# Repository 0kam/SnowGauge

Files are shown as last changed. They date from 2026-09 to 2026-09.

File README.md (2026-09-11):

<p align="center">
  <picture>
    <source media="(prefers-color-scheme: dark)" srcset="docs/assets/logo/logo_dark_800.png">
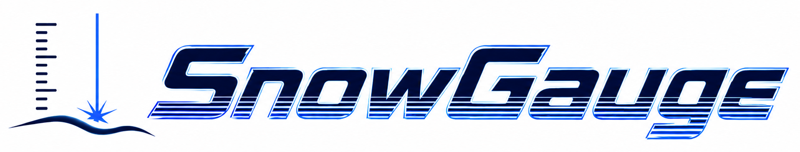
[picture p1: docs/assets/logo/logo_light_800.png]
SnowGauge
    
  </picture>
</p>

# SnowGauge

山岳・亜高山帯の無人サイトで 2 年間動く、低価格・低消費電力の積雪深ロガーです。
近赤外レーザー測距（TFmini Plus）で雪面までの斜距離を測り、IMU の傾斜で補正して積雪深に換算します。
スマホ（Android Chrome）の Web Bluetooth ページで時刻合わせ・データ回収・設定を行い、電池だけで越冬します。

*SnowGauge is a low-cost, low-power snow-depth logger (NIR laser ToF + XIAO nRF52840 Sense, Zephyr firmware, Web Bluetooth field app). Documentation is in Japanese; the developer docs (`firmware/README.md`, `docs/app/README.md`, `docs/record_format.md`) are in English.*

## はじめての方へ（この順に読む）

| 段階 | 読むもの | 内容 |
|---|---|---|
| 1. 部品を買う | [docs/01_parts.md](docs/01_parts.md)（[CSV](docs/01_parts.csv)） | 購入リスト。基板版・ブレッドボード版・TSD20 版の差分 |
| 2. 組み立てる | [docs/02_assembly.md](docs/02_assembly.md) | ブレッドボード（[配線ガイド](https://0kam.github.io/SnowGauge/breadboard_guide.html)）／基板 v1.2／筐体（検討中） |
| 3. ファームを書く | [docs/03_firmware.md](docs/03_firmware.md) | [Release](https://github.com/0kam/SnowGauge/releases) からダウンロードして USB で書き込み |
| 4. アプリを入れる・使う | [docs/04_app.md](docs/04_app.md) | **アプリ: https://0kam.github.io/SnowGauge/app/** 設置時・巡回時の手順 |
| 5. データを見る | [docs/05_data.md](docs/05_data.md) | CSV の列、品質フラグ、積雪深の再計算 |

文書一覧と「どこを直すとき何を更新するか」は [docs/README.md](docs/README.md) にあります。

## 現地アプリ

スマホの Chrome で https://0kam.github.io/SnowGauge/app/ を開き「ホーム画面に追加」すると、圏外でも起動するアプリになります（[使い方](docs/04_app.md)）。本体なしで画面を試すには [デモ表示](https://0kam.github.io/SnowGauge/app/?demo=1)。

<table align="center"><tr>
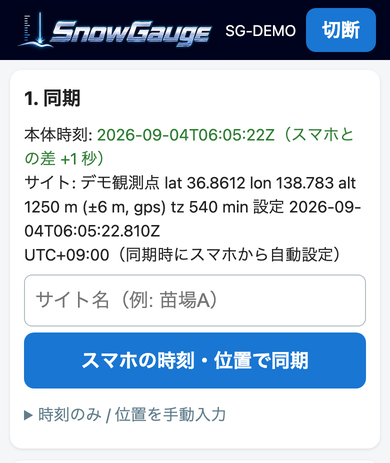
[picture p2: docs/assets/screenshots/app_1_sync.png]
同期
  <td valign="top" width="25%"></td>
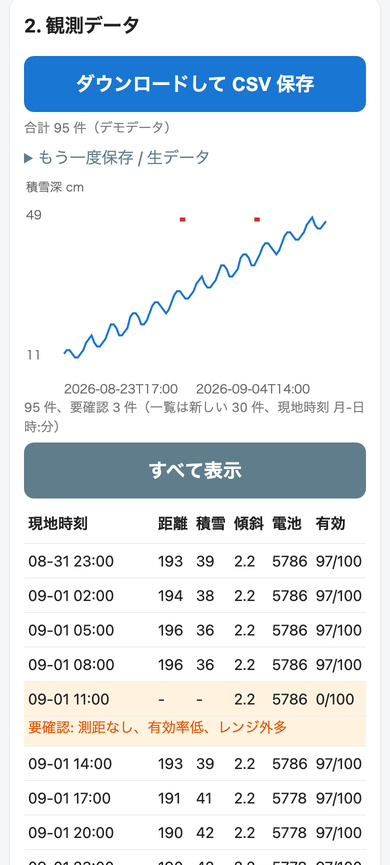
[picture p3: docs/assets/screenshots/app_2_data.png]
観測データ
  <td valign="top" width="25%"></td>
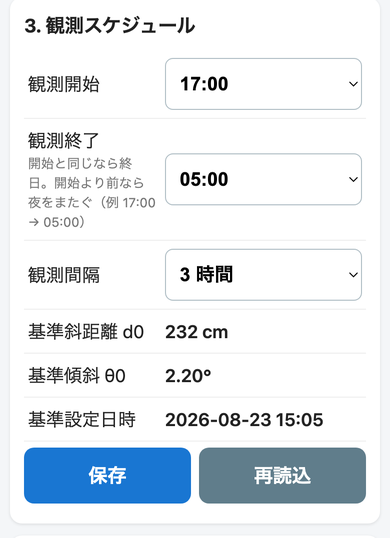
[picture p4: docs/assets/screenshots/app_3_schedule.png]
観測スケジュール
  <td valign="top" width="25%"></td>
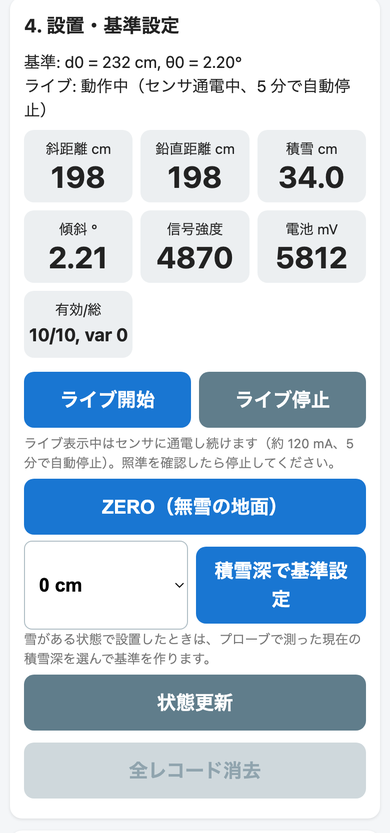
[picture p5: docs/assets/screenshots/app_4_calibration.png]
設置・基準設定
  <td valign="top" width="25%"></td>
</tr><tr>
  <td align="center">1. 同期</td><td align="center">2. 観測データ</td><td align="center">3. スケジュール</td><td align="center">4. 設置・基準設定</td>
</tr></table>

## 主な仕様

- 測距: TFmini Plus（近赤外 ToF）。安価な代替として TSD20 版を A/B 比較予定
- MCU: Seeed XIAO nRF52840 Sense（BLE、IMU 内蔵）、Zephyr（nRF Connect SDK v3.4.0）
- 電源: リチウム単 3（Energizer L91）×4。実測スリープ 26 µA（BLE アドバタイズ込み）、測定 1 回 0.037 mAh
- 記録: 40 バイト/回、QSPI フラッシュ上の LittleFS ＋ 内蔵フラッシュへのミラー。8 回/日で 2 年以上
- 通信: BLE（アドバタイズに電池・件数・最終値、SMP でファイル取得と時刻同期、キャリブレーション用 GATT）
- 現地 UI: Web Bluetooth ページ（PWA、オフライン動作、手袋前提の大きなボタン）

## 開発者向け

- 設計仕様書（要件・設計判断・改版履歴）: [SnowGauge_設計仕様書_v0.16.md](SnowGauge_設計仕様書_v0.16.md)
- 基板（KiCad、ガーバー、ピンマップの正）: [pcb/README.md](pcb/README.md)
- ファームウェアのビルド・シェル: [firmware/README.md](firmware/README.md)
- アプリの構成（SMP クライアントの流用方法）: [docs/app/README.md](docs/app/README.md)
- レコード形式・CSV 列定義: [docs/record_format.md](docs/record_format.md)
- 作業引き継ぎ（AI エージェント向け）: [CLAUDE.md](CLAUDE.md)

## 状態（2026-09-04）

基板 v1.2 発注済み（到着 9/10 ごろ）。ブレッドボードでファームウェア（ステップ 1〜4）とアプリの実機確認まで完了。TSD20 版ファームウェア（ステップ 5）は実装・ビルド済みで、ブレッドボード（U2 を F33 に差し替え）での実機確認待ち。次は基板到着後の再測定、筐体。

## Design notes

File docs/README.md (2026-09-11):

# SnowGauge 文書一覧と更新マップ

## 読む順（ユーザー向け）

| # | 文書 | 対象 | 内容 |
|---|---|---|---|
| 1 | [01_parts.md](01_parts.md) / [01_parts.csv](01_parts.csv) | 部品を買う人 | 購入リスト（BOM の唯一の正） |
| 2 | [02_assembly.md](02_assembly.md) | 組み立てる人 | ブレッドボード、基板 v1.2、筐体（検討中） |
| 2' | [breadboard_guide.html](https://0kam.github.io/SnowGauge/breadboard_guide.html) / [breadboard_guide_tsd20.html](https://0kam.github.io/SnowGauge/breadboard_guide_tsd20.html) | 同上 | ブレッドボード配線の図解（生成物。TFmini Plus 版 / TSD20 版、§5 に組み替え手順） |
| 3 | [03_firmware.md](03_firmware.md) | 書き込む人 | Release からのダウンロードと USB 書き込み |
| 4 | [04_app.md](04_app.md) | 現地作業する人 | アプリのインストールと設置・巡回手順 |
| 5 | [05_data.md](05_data.md) | 解析する人 | CSV の読み方、品質フラグ、再計算 |

## 技術文書（開発者向け）

| 文書 | 内容 |
|---|---|
| [../SnowGauge_設計仕様書_v0.16.md](../SnowGauge_設計仕様書_v0.16.md) | 要件・設計判断・電力収支・改版履歴。全文改版制（変更のたびに版を上げてファイル名も変える） |
| [../pcb/README.md](../pcb/README.md) | **ピンマップと電気トポロジの正**。基板は `pcb/generate_board.py` から生成（手編集禁止） |
| [../firmware/README.md](../firmware/README.md) | ビルド、書き込み、ベンチ用シェルコマンド |
| [record_format.md](record_format.md) | 40 バイトレコード、フラッシュ配置、CSV 列定義 |
| [coordinate_system.md](coordinate_system.md) | **基板の取付姿勢と IMU 座標系、tilt / pitch / roll の定義の正**（図付き） |
| [app/README.md](app/README.md) | Web Bluetooth ページの構成と他ロガーへの流用 |
| [tsd20_protocol.md](tsd20_protocol.md) | TSD20（廉価版センサ）の UART 仕様とファームウェア変種の実装メモ |
| [measurements/](measurements/) | 実測記録（`YYYY-MM-DD_topic.md`） |
| [archive/](archive/) | 旧版（v1.2 以前の回路。使わないこと） |
| [../CLAUDE.md](../CLAUDE.md) | AI エージェント向けの作業引き継ぎ（現状・決定事項・次の一手） |

## 更新マップ：何を変えたら、どの文書を直すか

| 変更 | 必ず更新するもの | あわせて確認 |
|---|---|---|
| **ピン割り当て・回路トポロジ** | `pcb/generate_board.py` → 再生成・DRC・ガーバー、`pcb/README.md`、`firmware/boards/*.overlay`、`docs/gen_breadboard.py`（PARTS）→ `breadboard_guide.html` と `--tsd20` で `breadboard_guide_tsd20.html` を再生成、`docs/assets/figures/gen_component_orientation.py`（部品の向きの図）を再実行 | 02_assembly.md、01_parts.md、仕様書 §4、CLAUDE.md の Key GPIO |
| **部品・数量・購入先** | `docs/01_parts.md` と `01_parts.csv` | 仕様書 §6（要約のみ）、`pcb/README.md` の追加部品欄 |
| **レコード形式**（フィールド追加・版上げ） | `firmware/src/record.h/.c`、`docs/record_format.md`、`docs/app/app.js` の `RECORD_SCHEMA`、`tools/decode_records.py` | 05_data.md、仕様書 §4.4 |
| **CSV の列** | `docs/app/app.js` の `CSV_COLUMNS`/`exportCSV`、`docs/record_format.md` | 05_data.md |
| **設定キー**（スケジュール・基準など） | `firmware/src/config.h/.c`、`docs/app/app.js` の `SETTINGS_SCHEMA` | 04_app.md、仕様書 §4.6 |
| **BLE**（アドバタイズ内容・GATT・SMP） | `firmware/src/ble_adv.h`、`cal_gatt.h`、`docs/app/app.js`/`smp.js` | 仕様書 §12、04_app.md |
| **アプリ UI** | `docs/app/index.html`、`app.js`（`APP_VERSION` を上げる）、`sw.js`（`CACHE` 名を上げる） | 04_app.md（ボタン名を一致させる） |
| **ファームウェアのリリース** | GitHub Release（タグ `fw-YYYY-MM-DD`、.uf2 / _dfu.zip / .hex）、`docs/03_firmware.md` のリンク | `firmware/README.md`、CLAUDE.md |
| **電流・電池寿命の実測** | `docs/measurements/YYYY-MM-DD_*.md` | 仕様書 §7.1、README の主な仕様 |
| **基板の取付姿勢・傾斜の定義** | `firmware/src/tilt_lsm6dsl.c`、`Kconfig` の `SNOWGAUGE_SENSOR_AXIS`、`docs/coordinate_system.md` と `docs/assets/figures/gen_coordinate_system.py`（図を再生成） | record_format.md、05_data.md、02_assembly.md、仕様書 §4.5 |
| **設計判断の変更** | 仕様書（版を上げ、§14 改版履歴に 1 行） | CLAUDE.md の決定事項 |

原則: 同じ事実を 2 か所に書かない。書く場合は片方を「正」と決めてもう片方からリンクする。

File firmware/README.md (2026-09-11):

# SnowGauge firmware

Zephyr / nRF Connect SDK application for the Seeed XIAO nRF52840 Sense on
SnowGauge PCB v1.2 (or the equivalent breadboard, `docs/breadboard_guide.html`).

- SDK: **nRF Connect SDK v3.4.0** (installed with `nrfutil sdk-manager`)
- Board target: `xiao_ble/nrf52840/sense`
- Pin map source of truth: [`pcb/README.md`](../pcb/README.md)
- User-facing docs (Japanese): [`docs/03_firmware.md`](../docs/03_firmware.md) (flashing), [`docs/04_app.md`](../docs/04_app.md) (field app), [`docs/05_data.md`](../docs/05_data.md) (data)

## Status: step 5 verified (2026-09-07) — TSD20 sensor variant runs on the breadboard; steps 1–4d complete and verified (32 µA sleep incl. adv)

| Module | File | Purpose |
|---|---|---|
| Sensor rail | `src/sensor_rail.c` | D10 = SENSOR_EN. Parks the sensor UART (pins Hi-Z) *before* cutting the rail (ghost-power countermeasure); calls `lidar_start()` once the rail is up |
| LiDAR | `src/lidar.h`, `src/lidar.c` | Sensor abstraction: interrupt-driven UART receiver, N-sample burst → median / variance / quality counters. Sets the baud rate at run time from the backend. Backend chosen by the Kconfig choice `SNOWGAUGE_SENSOR` |
| TFmini Plus | `src/tfmini.c` | Default backend: 9-byte frames, cm, strength + chip temperature, 115200 baud, frame-rate / save commands |
| TSD20 | `src/tsd20.c` | `overlay-tsd20.conf` backend: 4-byte frames, mm → cm, sentinel 50000, no strength / temperature, 460800 baud, "start ranging" after the rail settles, frame-rate command. Protocol: `docs/tsd20_protocol.md` |
| Battery | `src/battery.c` | A0 via SAADC (gain 1/6, 40 µs acquisition for the 500 kΩ source). Valid only while the rail is on; Vbat = node × 2 |
| Tilt | `src/tilt.h`, `src/tilt_lsm6dsl.c` | `TiltSensor` abstraction; LSM6DS3TR-C implementation (accel only, 52 Hz burst, powered down between reads). Deferred init: the board's regulator delay is too short for the chip. Tilt = angle between gravity and the LiDAR axis in the IMU frame: **−Y** (PCB vertical in the enclosure: USB left, sensor terminal J2 up; default since 2026-09-11), +Y (the 2026-09-07 mount, USB right) or ±Z (flat board, `overlay-flat.conf`); definitions and figure in `docs/coordinate_system.md` |
| Measure | `src/measure.c` | tilt → rail on → Vbat → N frames → Vbat → rail off; `sensor_lock` mutex shared with the calibration live mode. 0 frames → one power-cycle retry (`CONFIG_SNOWGAUGE_LIDAR_RETRY`, 1 s off, TSD20 gets stop → start), record flag RETRIED |
| Power | `src/power.c` | Green LED pulse; checks that the QSPI flash runs under runtime PM (deep power-down between accesses) |
| USB PM | `src/usb_pm.c` | USB device enabled only while VBUS is present (board default keeps HFXO+USBD on: 1.8 mA) |
| Record | `src/record.c` | 40-byte record v1 encode/decode with CRC-16 (`docs/record_format.md`); flag bit 6 marks records from the TSD20 build |
| Storage | `src/storage.c` | LittleFS on the QSPI (`/lfs1/rec_YYYYMM.bin`) + raw append-only mirror in internal flash; restores clock/seq at boot |
| Clock | `src/timekeeping.c` | Emulated RTC behind the `rtc` alias; UNSET / ESTIMATED / SYNCED state. Checkpoint in NVS (`sgt/epoch`) every `CONFIG_SNOWGAUGE_TIME_SAVE_MIN` (60) and 2 s after every external sync; at boot the later of the newest record and the checkpoint seeds the estimate |
| Config | `src/config.c` | Zephyr settings (`sg/sched/*`, `sg/cal/*`) exposed over the SMP settings group; scheduler (local time window + interval, tz offset) and the calibration reference d0/θ0 |
| BLE adv | `src/ble_adv.c` | Connectable advertising 1–2 s, name `SG-TFM-XXXX` (TSD20 build: `SG-TSD-XXXX`), Manufacturer Data with Vbat / record count / last distance / flags (layout in `ble_adv.h`); restarts advertising after a disconnect |
| SMP | `src/smp_mgmt.c` | mcumgr hooks: os datetime get/set → app clock, fs access hook (a read of `rec_*.bin` unlocks the BLE ERASE), over BLE and over the USB shell |
| Calibration GATT | `src/cal_gatt.c` | Custom service (UUIDs in `cal_gatt.h`): live notify (dist/strength/tilt/vbat/quality, 5 min timeout, stops on disconnect), control write (live on/off, ZERO, reference from probed depth, ERASE + token), status read (d0/θ0/set epoch/live/busy/seq) on its own work queue |
| Diag | `src/diag.c` | Reset cause (hwinfo, cleared after reading), consecutive-reset counter in NVS (`sgd/boots`; GPREGRET2 is wiped by a watchdog reset, measured 2026-09-07), fatal reason in GPREGRET2 (soft reset only), hold-off, measurement halt past `CONFIG_SNOWGAUGE_BOOT_MAX_RESETS` resets, one line per boot in `/lfs1/boot.log`; `k_sys_fatal_error_handler` reboots on exceptions/panics instead of halting |
| Watchdog | `src/wdt_mon.c` | nRF52 WDT (`CONFIG_SNOWGAUGE_WDT_TIMEOUT_S` = 120 s, runs in sleep) fed by a supervisor on the system work queue only while the scheduler loop (2 h), a running measurement (60 s) and BLE advertising are all alive |
| Shell | `src/shell_cmds.c` | Bench commands over USB CDC ACM (table below) |

Phone / PC UI: the Web Bluetooth page at **https://0kam.github.io/SnowGauge/app/** (source `docs/app/`, see `docs/app/README.md`). Bench SMP from the Mac: `tools/smp_datetime.py` (pip install smpclient); shell scripting: `tools/sgshell.py` (pyserial). Sleep-current results: `../docs/measurements/2026-09-03_breadboard_current.md`. The TSD20 variant (step 5) was verified on the breadboard on 2026-09-07 (U2 = NJU7223F33, `docs/breadboard_guide_tsd20.html`): 100 frames / 499 ms, 0 checksum errors, records flagged SENSOR_TSD20, one measurement = 0.0098 mAh, sleep 36 µA (`docs/measurements/2026-09-07_tsd20_breadboard_current.md`). The TFmini build after the lidar refactor was re-verified the same day (100 frames / 1010 ms, name `SG-TFM-XXXX`). Details in `docs/tsd20_protocol.md`.

## Prebuilt binaries

Firmware builds are published as GitHub Releases, tag `fw-YYYY-MM-DD`. Current:
**https://github.com/0kam/SnowGauge/releases/tag/fw-2026-09-07**

| Asset | Use |
|---|---|
| `snowgauge_fw_2026-09-07b.uf2` | UF2 drag-and-drop onto the `XIAO-SENSE` drive (Windows / Linux / older macOS) |
| `snowgauge_fw_2026-09-07b_dfu.zip` | Serial DFU package for `adafruit-nrfutil` (required on macOS 26); already built with `--sd-req 0xFFFE` |
| `snowgauge_fw_2026-09-07b.hex` | Application hex (linked at 0x27000) for building your own package |
| `snowgauge_fw_2026-09-07b_tsd20.uf2` / `_tsd20_dfu.zip` / `_tsd20.hex` | The same three files for the **TSD20 variant** (U2 = NJU7223F33; BLE name `SG-TSD-XXXX`) |

Step-by-step flashing instructions for non-developers: [`docs/03_firmware.md`](../docs/03_firmware.md). The app requires this release or newer (settings group + calibration service).

## Build

One-time: install nrfutil and the SDK (already done on the dev Mac; `~/.local/bin/nrfutil`).

```bash
nrfutil sdk-manager install v3.4.0
```

Build inside the SDK toolchain environment. `west` must be started from the SDK workspace (`/opt/nordic/ncs/v3.4.0`), so pass absolute paths:

```bash
cd /opt/nordic/ncs/v3.4.0 && nrfutil sdk-manager toolchain launch --ncs-version v3.4.0 -- west build -d "$REPO/firmware/build" -b xiao_ble/nrf52840/sense "$REPO/firmware"
```

Add `-p` after `west build` for a pristine rebuild; `-- -DEXTRA_CONF_FILE=overlay-auto60.conf` builds the bench variant that measures every 60 s. Output: `firmware/build/firmware/zephyr/zephyr.uf2` and `zephyr.hex` (sysbuild layout).

Host regression check: run `python3 firmware/tests/test_regressions.py` from the repository root (Python 3 and `cc` required). It runs the firmware functions with stubbed hardware/settings to check reset backoff, BLE wakeups, measurement success and settings errors; it does not validate hardware timing or brown-outs.

**Sensor variants** (Kconfig choice `SNOWGAUGE_SENSOR`, same board overlay, same pins):

| Build | Sensor / U2 | Extra args | BLE name |
|---|---|---|---|
| default | TFmini Plus / NJU7223F50 (5 V) | none | `SG-TFM-XXXX` |
| TSD20 | PONO TSD20 / NJU7223F33 (3.3 V) | `-- -DEXTRA_CONF_FILE=overlay-tsd20.conf` (use a separate build dir, e.g. `-d firmware/build-tsd20`) | `SG-TSD-XXXX` |

`overlay-flat.conf` selects the flat-board tilt axis (IMU Z) for a breadboard lying on the bench; without it a flat board reads tilt ≈ 90°. The previous vertical mount (USB right) is `CONFIG_SNOWGAUGE_SENSOR_AXIS_POS_Y=y` in a conf fragment of its own. Both overlays can be combined: `-DEXTRA_CONF_FILE="overlay-tsd20.conf;overlay-auto60.conf"`. A TSD20 build on a TFmini board (or vice versa) is harmless but reads no distance (`lidar info` shows which variant is running).

## Flash (stock Adafruit bootloader, no debugger needed)

The app is linked at 0x27000, after the Adafruit bootloader, so the bootloader is preserved and the board can always be re-flashed.

**UF2 (Windows / Linux / older macOS):** disconnect the battery (**never USB and battery at the same time** unless jumper ⑩ is pulled — see the breadboard guide), connect USB-C, double-tap reset, copy `firmware/build/firmware/zephyr/zephyr.uf2` onto the `XIAO-SENSE` drive.

**Serial DFU (needed on macOS 26, which cannot mount the XIAO's UF2 drive):**

```bash
pip install adafruit-nrfutil
adafruit-nrfutil dfu genpkg --dev-type 0x0052 --sd-req 0xFFFE --application firmware/build/firmware/zephyr/zephyr.hex snowgauge.zip
```

Put the board in the bootloader (double-tap reset, or type `dfu` in the firmware shell), then:

```bash
adafruit-nrfutil dfu serial --package snowgauge.zip -p /dev/cu.usbmodem* -b 115200 --singlebank
```

`--sd-req 0xFFFE` (any SoftDevice) matters: with `0x00` the bootloader rejects the package and resets mid-transfer.

Release assets are produced from the same build: `zephyr.uf2` and `zephyr.hex` renamed, plus the `genpkg` zip above. The TSD20 build goes into the same release tag as `snowgauge_fw_<date>_tsd20.uf2` / `_tsd20_dfu.zip` / `_tsd20.hex`.

## Shell (USB CDC ACM, prompt `sg:~$ `, 115200)

Open the USB serial port (`/dev/cu.usbmodem*`, `COMx`, `/dev/ttyACM0`) with e.g. `screen`, Tera Term or `tools/sgshell.py`, press Enter for the prompt.

| Command | Purpose |
|---|---|
| `help` | list commands (`cal` and `cfg` present = step 4d firmware) |
| `rail on` / `rail off` / `rail status` | sensor rail (boots OFF; `rail off` parks the UART first) |
| `lidar raw [ms]` | live frames for `ms` (needs `rail on`); TSD20 build prints mm |
| `lidar read [n] [timeout_ms]` | n-frame burst: median / variance (+ strength / temperature on the TFmini) |
| `lidar rate <hz>` / `lidar save` | sensor frame rate (TFmini: volatile until saved; TSD20: no save command) |
| `lidar info` | sensor variant, baud, capture parameters, Vbat guard |
| `lidar bytes [ms]` / `lidar baud <rate>` / `lidar start` / `lidar tx <hex…>` | debug: raw RX hex dump, run-time baud change, send the start-streaming command, send arbitrary bytes |
| `tfmini …` / `tsd20 …` | alias of `lidar` in the matching build (old scripts keep working) |
| `batt` | battery voltage (pulses the rail if it is off) |
| `tilt [n]` | IMU tilt / pitch / roll from n averaged samples |
| `measure` | one full cycle, stored as a record (flag MANUAL), printed as CSV |
| `auto [s]` | bench auto-measurement period (0 = off); overrides the schedule |
| `rec count` / `rec ls` / `rec dump [n]` / `rec hex [n]` | record count + storage state / files on `/lfs1` / newest n records as CSV (0 = all) / raw hex for `tools/decode_records.py --hex` |
| `rec erase ERASE` | delete all record files + erase the mirror |
| `time [set <epoch>]` | show / set the clock (UTC seconds, `date +%s`); shows synced / estimated / unset |
| `cfg show` | schedule, tz, calibration reference, next scheduled measurement |
| `cfg sched <HH:MM> <HH:MM> <interval_min> [tz_min]` | set the schedule (start == end: all day; start > end: spans midnight; interval 0: off) |
| `cal zero [depth_cm]` | take the reference (ZERO on bare ground, or from a probed snow depth: `d0 = d + depth/cos(tilt)`) |
| `cal clear` | clear the reference |
| `cal live [off]` | live-mode state; `off` stops it (start only from the BLE page) |
| `ble [adv <min_ms> [max_ms]]` | advertising status / interval (`ble adv 0` stops) |
| `diag [log]` | reset cause / boot counter / last fatal reason; `log` also prints `/lfs1/boot.log` |
| `wdt [stall main\|measure\|ble]` | watchdog supervisor status; `stall` simulates a stuck subsystem (reset within ~150 s) |
| `hang` / `fault` / `panic` | TEST: lock the CPU (watchdog reset after 120 s) / CPU exception / `k_panic()` (both reboot through the fatal handler; `diag` on the next boot shows `fatal=…`) |
| `reboot` | warm reset into the application |
| `dfu` | reboot into the Adafruit bootloader (then run `adafruit-nrfutil dfu serial`) |
| `device list`, `sensor get lsm6ds3tr-c@6a` | Zephyr built-ins (debug) |

Bench test (breadboard STEP 5 / PCB bring-up): `rail status` → `rail on` (sensor node = 5 V with the TFmini LED on / 3.3 V for the TSD20) → `lidar raw 500` → `lidar read 100` → `batt` → `rail off` (sensor node = 0 V) → `measure`. Measured on the breadboard (2026-09-03, 6 V bench supply): `vbat = 5624 mV`, 100 frames / 997 ms, `cksum_err=0`, median 197 cm, strength ~6830, chip temp 65 °C. If the TFmini stays dimly alive with the rail off, the UART is not parked — check that `rail off` returned 0.

Boot behaviour worth knowing on the bench: the first *scheduled* measurement is held off for 10 min × consecutive-reset count (`CONFIG_SNOWGAUGE_BOOT_HOLDOFF_MIN`, multiplier capped at 12); `measure` and `auto` bypass this hold-off. The NVS counter clears after the first attempted sensor rail burst whose record is successfully stored (manual or scheduled), or on BLE connection; elapsed time alone never clears it. This proves the board survived the rail load, not that the sensor returned a valid distance: zero valid frames or capture errors still clear the counter when the record is stored. Bursts skipped by the low-battery guard (`lidar_ret == -ENOTSUP`), measurement-cycle errors and storage failures retain the counter. At `CONFIG_SNOWGAUGE_BOOT_MAX_RESETS` (12), scheduled measurements (including `auto`) halt while BLE keeps advertising (flag MEAS_HALTED). **Rebooting or power-cycling alone does not recover a halted unit.** Connect over BLE to drop the halt and multiplier immediately (the base 10 min hold-off remains), or run a manual `measure` with a non-skipped burst and successfully store its record, then reboot. Counter-clear write failures are logged and retried on the next stored, non-skipped burst or BLE connection. Vbat < 4600 mV skips the TFmini burst. Every boot appends a line to `/lfs1/boot.log` (`diag log`), e.g. `~2026-09-07T10:00:00Z boot=2 cause=watchdog fatal=none hw=0x2 fw=TFmini Plus`.

## Shell output fields

`weak` = strength < 100 (Benewake: unreliable), `sat` = strength 65535 (over-exposed), `invalid` = distance sentinel (TFmini 0 / 65535 cm, TSD20 50000 mm) with acceptable strength, `cksum_err` = frames dropped by checksum. The TSD20 build has no `weak` / `sat` / strength / chip-temperature lines. `var` is the sample variance in cm² over the valid frames.

## Notes / decisions pending

- **No MCUboot / BLE DFU in v1 (decided 2026-09-02, spec v0.11)**: the XIAO ships with the Adafruit UF2 bootloader at 0x0 and installing MCUboot would overwrite it, which needs an SWD probe. The firmware is flashed over USB as UF2 / serial DFU; field updates mean opening the enclosure and plugging in USB (battery disconnected).
- Build reproducibility: the SDK version is pinned here (v3.4.0) and the build uses the SDK's own workspace. There is **no `west.yml` manifest in this repo**; add one for a self-contained workspace when the build moves to CI.
- No pairing: anyone nearby can erase (token-protected, and only after a download since boot) or change settings. PIN later if needed.
- WDT on since 2026-09-07 (120 s). The nRF52 WDT keeps running across a soft reset into the Adafruit bootloader; the bootloader (0.6.1 and later, `lib/sdk11/.../bootloader.c` `wait_for_events()`) feeds a running WDT in its DFU wait loop, so `dfu` + serial DFU keep working. Verify the bootloader version on a new board (it is the USB `bcdDevice` while in bootloader mode: `system_profiler SPUSBDataType`).

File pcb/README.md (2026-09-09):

# SnowGauge PCB v1.2 (TFmini Plus / TSD20 common board)

- Board: **64 x 50 mm**, 2-layer, all through-hole. Bottom layer is a GND pour.
- Mounting: 4x M3 (3.2mm) holes at the corners, **57 x 43 mm** center spacing (3.5mm from every edge; hole centers at (3.5, 3.5) / (60.5, 3.5) / (3.5, 46.5) / (60.5, 46.5) from the board's top-left corner).
- Fits the previous prototype enclosure (Takachi BCAP091208G, inner 66 x 96 mm) with the 50mm side across the width.
- Battery terminal J1 exits at the bottom edge; TFmini terminal J2 exits at the right edge.
- Generated programmatically: [generate_board.py](generate_board.py) → `SnowGauge.kicad_pcb` (KiCad 10). DRC: 0 errors, 0 unconnected.
- One board serves both variants: **U2 = NJU7223F50 for TFmini Plus / NJU7223F33 for TSD20** (same pinout).

## Ordering (JLCPCB, ~1 week to Japan)

1. Go to jlcpcb.com → "Add gerber file" → upload `SnowGauge_v1.2_gerbers.zip`
2. Settings: 2 layers, 64x50mm (auto-detected), qty 5 (or 10), 1.6mm, HASL, green — all defaults are fine
3. Shipping: **DHL or OCS Express** (this is what makes it arrive in ~3-4 days; economy mail takes weeks)

## Firmware pin map (matches this board — the single source of truth)

| XIAO pin | Net | Function |
|---|---|---|
| A0 (D0) | ADC_NODE | Battery voltage = reading x2. Divider hangs on VBAT_SW, so **enable SENSOR_EN, then read A0** (v1.2: Q3/R6/D3 deleted — node is 0V during sleep, never above VDD) |
| D4 / D5 | I2C_SDA / I2C_SCL | Spare I2C header J3 (future external IMU) |
| D6 (TX) | UART_TX_MCU | → 1k (R7) → TFmini RX (white) |
| D7 (RX) | UART_RX | ← TFmini TX (green) |
| **D10** | SENSOR_EN | High = sensor rail ON (Q2→Q1). *Changed from D2 in the hand-wiring plan.* |
| 3V3 | 3V3_SYS | Powered from U1 (NJU7223F33) |

## Connectors

- J1 (screw terminal 2P, 5.08mm): battery + / − ("+"/"-" on silk)
- J2 (4 positions at 5.08mm = **two interlocked 2P blocks**): TFmini, top to bottom RED +5V / BLK GND / GRN TX / WHT RX
- J3 (pin header 1x4): SCL / SDA / GND / 3V3 spare I2C
- A1: 2x low-profile 1x7 female headers (2.54mm) — socket for XIAO nRF52840 Sense

## Extra BOM lines (in addition to spec §6)

| Part | Qty | Note |
|---|---|---|
| Screw terminal block 2P, **5.08mm pitch, interlocking** (TB111-2 / MKDS-1,5 type) | 3 | J1 battery; J2 = 2 blocks snapped together (4 contiguous positions) |
| Female pin socket 1x7, 2.54mm | 2 | XIAO socket. Holes are 0.89mm: fine for round machined tails (~0.5mm) and typical stamped tails; avoid 0.64mm square-tail types |
| 10uF radial MLCC, **5mm lead pitch** | 1 | C6. A 2.5mm-pitch part needs its leads splayed |
| Pin header 1x4, 2.54mm | 1 | J3 (optional) |
| M3 screws/standoffs | 4 | mounting holes at corners |

The consolidated BOM for a whole unit (spec §6 parts + these lines, corrected counts, breadboard consumables, TSD20 variant) is [docs/01_parts.md](../docs/01_parts.md) / [docs/01_parts.csv](../docs/01_parts.csv).

## Safety notes silkscreened on the board

- "NO USB WHILE BATTERY CONNECTED!" — disconnect battery before plugging USB into the XIAO
- C4 (OS-CON) polarity marked; D1 cathode marked "K"

## Component orientation (U1, U2, Q1, Q2)

The KiCad TO-220 / TO-251 vertical footprints put the reference designator on the **metal-tab side**, so the part's **marked (printed) face points the other way**. With the board held "SnowGauge v1.2" up / J1 down: U1 and Q1 have the tab towards the top edge (print facing the XIAO), U2 and Q2 are rotated 180 deg (tab towards the board centre, print facing the top edge). Assembly instructions with a figure: [docs/02_assembly.md](../docs/02_assembly.md) B-2 (figure regenerated by `docs/assets/figures/gen_component_orientation.py`).

## v1.2 changes (post-review)

- **Battery divider now fed from VBAT_SW** (the switched rail) instead of VBAT: the ADC node sits at 0V during sleep instead of floating to ~7V through the nRF52840's clamp diode (abs-max violation found in review). Q3, R6 and the D3 GPIO are deleted. Firmware measures battery by enabling SENSOR_EN and reading A0 (x2).
- **USB corridor cleared**: U1 and C1 moved to the top-left, D1 lowered — a USB-C cable now reaches the socketed XIAO for flashing.
- TFmini wire-order legend moved where it stays visible after C4 is mounted.
- Terminals changed to **3x 5.08mm 2P blocks**; the TFmini pair interlocks into one 4P unit on contiguous 5.08mm positions (J2). Standard Akizuki TB111-class parts drop in.

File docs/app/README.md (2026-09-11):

# SnowGauge Web Bluetooth page

Single-page app for site visits: sync time / timezone / location, download
records (CSV + raw), change the observation schedule, aim and ZERO the sensor.
Talks SMP (mcumgr) over Web Bluetooth plus the small calibration GATT service.

- **Public URL: https://0kam.github.io/SnowGauge/app/** (GitHub Pages from `docs/`).
- **Required firmware: Release `fw-2026-09-04` or newer** (SMP settings group +
  calibration service). Older firmware logs "本体 FW が設定グループ未対応".
- Version string: `APP_VERSION` in `app.js`, shown under the log panel as
  「アプリ版 YYYY-MM-DDx」. Bump it and the cache name in `sw.js` on every release.
- Usage instructions for field staff (Japanese): [`../04_app.md`](../04_app.md).
- Works in Chrome on Android and on PC (Windows/macOS/Linux). iPhone Safari has
  no Web Bluetooth; use a Web-Bluetooth browser app (e.g. Bluefy).
- Must be served over HTTPS (GitHub Pages) or from `localhost`. Installs as a
  PWA and caches itself for offline use in the field (offline-first; a new
  version is picked up on the next online load and applied on the next start).
- Local test: `python3 -m http.server 8787 --directory docs/app` then open
  http://localhost:8787/ in Chrome.

Files: `cbor.js` (CBOR), `smp.js` (generic SMP client: os / fs / settings
groups), `app.js` (SnowGauge specifics: record schema, settings schema,
calibration panel, CSV), `index.html`, `sw.js` + `manifest.webmanifest` (PWA).

Saving files: `saveFiles()` clicks an `<a download>` (Android / PC) and, on iOS,
also offers `navigator.share({files})` plus a copy / new-tab view — WKWebView
browsers such as Bluefy ignore the download attribute silently, so the anchor
alone saves nothing there. The share call needs live user activation, hence the
separate 「共有して保存」 button. CSV is UTF-8 with a BOM and CRLF; the 文字コード picker
(`CSV_ENCODINGS`) also writes Shift_JIS (CP932 table built at run time from
`TextDecoder`, since there is no `TextEncoder` for legacy encodings) because
Excel for Mac reads CSV as Shift_JIS whatever the BOM says. Sheets on Android
reads Latin-1 whatever the file is - no encoding fixes that one.

Reusing for another logger: keep `cbor.js` / `smp.js`, replace the two schemas
and the calibration panel in `app.js`.

Demo mode: append `?demo=1` to the URL to populate the page with sample data without a device (used for the README screenshots and for training).

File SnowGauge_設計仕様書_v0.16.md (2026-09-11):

# SnowGauge 設計仕様書 v0.16

- 版: v0.16(2026-09-11)
- プロジェクト: 積雪深計開発(予算: 適応三型)
- 名称: **SnowGauge(確定)**
- 目的: 遠隔地(亜高山帯)の積雪・融雪過程を継続モニタリングする安価な積雪深ロガーの開発と多点展開
- 運用ポリシー: 本仕様書を唯一の真実(single source of truth)とし、変更時は毎回全文改版する。ただし**ピンマップ・電気トポロジは `pcb/README.md`(PCB v1.2)が正**で、本書と食い違う場合はそちらを優先する

---

## 1. 背景と経緯

- プロトタイプ(Spresense + 拡張ボード構成)は完成済み。2025-26 冬の試験で電池消耗により失敗。原因は **SD カードを含む Spresense 拡張ボードの待機電力**と特定。
- 本仕様書は 2026-27 冬の既製品比較試験(既存積雪深計サイト 3 箇所)に向けた改良版の設計を定める。
- 上位文脈: 適応三型・柱②「積雪深モニタリングの追加」。**安価に大量設置できること**が価値の中核。
- v0.8 で廉価側 LiDAR を **TSD20** に交代(耐環境光 8m@100kLux・3.3V 駆動)。5V レールを削除し**単一電圧アーキテクチャ**へ。UART 直結確認と幽霊給電対策を反映。
- v0.10 で PCB v1.2 を発注、v0.11〜v0.12 でファームウェア(ステップ 1〜4)と Web Bluetooth ページを実装し、ブレッドボードで電流実測まで完了(§7.1、§12)。

## 2. 要件

### 2.1 マスト

| # | 要件 | 数値目標 |
|---|---|---|
| R1 | 雪面までの距離測定 | 斜距離 ≦5m 設計(取付高 ~4m + θ25°)、誤差 ±数 cm 級 |
| R2 | 定期測定・記録 | 1 日数回(基準: 8 回/日)、時刻付き。TSD20 は日中測定可(8m@100kLux)。TFmini 機との比較整合のため夜明け前+日没後を共通コアに、日中も測定しフラグ付与(§4.1 ②) |
| R3 | 電池寿命 | エナジャイザー L91 リチウム単三 4 本で **2 年ノーメンテ** |
| R4 | 取付 | 樹幹等に斜め取付(θ ≦ 30°)。加速度センサで角度補正 |
| R5 | 動作環境 | 厳冬期の亜高山帯、**-20℃ 保証**(センサ仕様に合わせ -30℃ 要件は撤回) |
| R6 | 測距波長 | **850–905nm 帯**(1550nm 帯は禁止。§4.2) |
| R7 | 品質フラグ | 測距の信号強度・ばらつき・レンジ外頻度をレコードに記録 |

### 2.2 したい

- 巡回時に筐体を開けずにデータ回収・死活確認・時刻同期(BLE)
- 設置時キャリブレーション(初期距離・初期傾斜角・照準先確認)をスマホで完結

### 2.3 将来

- LPWA(LoRaWAN)によるデータ転送(時刻同期は DeviceTimeReq で代替可)
- SWE 展開(§9)

## 3. 測距方式・センサ選定

### 3.1 方式(ゼロベース検討の結論)

主測距: **近赤外レーザー ToF** を採用。

| 方式 | 判定 | 理由 |
|---|---|---|
| NIR レーザー ToF | **採用** | ISO 23435:2022 認定方式。小スポット・cm 級・低電力化容易。降雪イベント中の信頼性でも超音波より優位が近年の業界評価 |
| 超音波(SR50 系) | 却下 | 温度補正必須、風・湿度影響、乾燥剤点検・トランスデューサ定期交換(6〜36 ヶ月)が「2 年ノーメンテ」と正面衝突。既製品=比較試験の相手 |
| ミリ波レーダー | 却下 | 乾雪が半透明(誘電率 ~1.2–1.5)で雪面計測に原理的に不向き |
| カメラ + 雪尺 | **併用** | 既存定点カメラ網 + yamami に相乗り。第 3 の独立系統(§10) |
| サーミスタ梯子 | 温存 | tidbit 運用の延長。粗いが故障モード独立の最安冗長系 |

### 3.2 LiDAR 選定(A/B 構成)

| | **TFmini Plus(上位側・先行実装)** | **TSD20(廉価側・展開主力候補)** |
|---|---|---|
| 価格 | ~¥7,000〜9,000 | ¥2,580(秋月 131304) |
| レンジ | 0.1〜12m、±5cm(0.1–5m) | 10m@反射率90% / **10m@10%** |
| 耐環境光 | 70kLux 級 | **8m@100kLux(日中測定可)** |
| 防水防塵 | **IP65** | なし(光学窓+フード必須、U5) |
| 出力 | 距離+**信号強度**+**チップ温度**(9B フレーム、100Hz) | 距離のみ(UART/I2C、200Hz 可変、レンジ外番兵 **50000**) |
| 電源 | 5V±0.5V、平均 ≤110mA、**ピーク 500mA**(実測バースト平均 ~115mA) | **3.3V 駆動**、測定時 ~50mA 級(見積り、要実測) |
| 波長 | **850nm**(水吸収帯から遠く湿雪に有利) | 905nm |
| 動作温度 | -20〜+60℃ | -20〜+60℃ |
| 基板 | 共通 PCB v1.2、U2 = NJU7223F50 | 共通 PCB v1.2、U2 = NJU7223F33 |

**方針: 今冬の比較試験を TFmini Plus vs TSD20 の A/B 対決も兼ねた設計にする。**「¥2,580 センサはどこまで戦えるか」自体を論文ネタ化し、多点展開の最終選定は冬の実データで決める。ファームウェアは TFmini Plus 機を先行して完成させ(§12)、TSD20 はフレーム形式と番兵値だけが異なるドライバ変種として追加した(v0.13、`firmware/src/lidar.h` の下に `tfmini.c` / `tsd20.c`。ビルド時に `overlay-tsd20.conf` で選択、BLE 名は `SG-TFM-XXXX` / `SG-TSD-XXXX`、レコード flags bit 6 = SENSOR_TSD20。プロトコルは `docs/tsd20_protocol.md`)。

経緯: v0.3〜v0.7 では廉価側を手持ちの TSD10(¥1,980、耐環境光 2m@100kLux、5V 駆動)としていたが、v0.8 で日中測定可・3.3V 駆動の TSD20 に交代し、TSD10 はベンチ反射試験(U2)用に回した。

TSD20 側の要注意点(TSD10 精査からの持ち越し分を含む):
- 信号強度出力なし → 品質フラグは「番兵値 50000 の頻度 + N 標本分散」で代替(分散は雪面状態量としても有用)
- ボーレートは既定の **460800** で実装(nRF52840 UARTE が対応。ブレッドボードで不良フレームが出れば 115200 に落とす。TFmini 機は 115200)
- 逆接・過電圧保護なし(電源シーケンス注意。本設計ではゲート後の LDO で供給)
- レンズ防塵に赤色透過板(905nm 透過率 ≧85%)が公式推奨 → 光学窓設計に流用可
- 高反射体(ミラー等)で誤動作リスク → 氷化クラスト面の鏡面反射に留意
- UART ロジックレベルは 3.3V(説明書記載。直結。ブレッドボードで実測予定、U12)

### 3.3 センサ読み

TSD20 は 200Hz(可変)、TFmini Plus は 100Hz のため、約 1 秒(TSD20 は約 0.5 秒)の通電で 100 サンプル取得できる。実装は **N=100 フレーム**を取り、チェックサム不良・番兵値(TFmini 0/65535cm、TSD20 50000mm)・飽和・弱信号(強度 <100、TFmini のみ)を除いた有効フレームから中央値+分散(+TFmini は強度中央値・チップ温度)を算出してレコードに記録する(§4.3、§4.4)。TSD20 は mm 分解能を cm に丸めて同じレコード形式に入れる(strength=0、lidar_temp=-32768)。

## 4. システム構成

### 4.1 全体図

```
L91×4 (開放7.2V → 終止4.0V)
 ├─ 1N5819 ショットキー(逆接保護)
 ├─ NJU7223F33 (U1) ── 3.3V常時レール ── XIAO nRF52840 Sense(内蔵IMU/温度/BLE/2MB QSPI)
 └─ [2SJ334 P-ch高側SW (Q1)] ─ VBAT_SW ─ センサ用LDO (U2) ─ +470µF OS-CON ─ LiDAR
      ・TSD20 機: NJU7223F33(3.3V) / TFmini Plus 機: NJU7223F50(5V)
      ・F33/F50 は同一ピン配置(VOUT-VIN-GND)→ **同一基板で LDO 差し替えのみの 2 バリアント**
                          (測定時のみ通電。遮断側レギュレータはIq不問)
 ゲート駆動: XIAO D10 (SENSOR_EN) → 10kΩ → 2SK4017 (Q2, 低側) → 2SJ334ゲート(100kΩでVBATへプルアップ=スリープ中確実OFF)
 電池電圧監視: 1MΩ+1MΩ分圧を**VBAT_SW(高側SW後)に接続** → XIAO ADC(A0)。スリープ中はレール遮断で0V
              (v0.10: 低側SW方式=Q3/R6/D3 を廃止——スリープ中にADCノードがVDD超過するため)
 UART: XIAO D6(TX) → 1kΩ → LiDAR RX / XIAO D7(RX) ← LiDAR TX。D4/D5 は予備 I2C(J3)
```

設計原則:
① **BLE 以外は測定時以外すべて電源断**(センサ系は高側スイッチで完全遮断)
② 測定時刻は夜明け前+日没後を共通コアに、日中も測定(TSD20 は 8m@100kLux で日中可。系統間比較の整合とデータの日変化捕捉のため全時刻フラグ付き記録)
③ **完全に電源遮断される側のレギュレータは Iq 不問**——電流容量と入手性だけで選ぶ
④ 昇圧なし。センサレールは電池から直接 LDO(ゲート後なので Iq 不問)
⑤ TSD20 機は 3.3V 単一電圧: LDO ドロップアウト 0.4V で **Vbat ~3.8V(電池ほぼ全容量)まで LiDAR 稼働**。TFmini 機(5V)のみ末期 1〜2 割で LiDAR スキップにフォールバック(FW の低電圧ガード、§4.3)

### 4.2 波長選定の根拠

- 近赤外(850〜940nm): 氷の吸収は中程度、雪中潜り込み数 cm 以下 → 雪面計測に最適
- 可視(532nm): 反射率は高いが雪中浸透が大きい
- 短波長赤外(1550nm): 雪の反射率 <10%、湿雪・大粒径でさらに悪化 → **禁止**
- 850nm(TFmini Plus)は 940nm より水の吸収帯から遠く、湿雪・融雪期にわずかに有利

### 4.3 測定シーケンス(実装済み: `firmware/src/measure.c`)

1. スケジューラ(§4.6)が次の測定時刻に起床(System ON スリープから。BLE アドバタイズは継続)
2. **センサ排他ロック**(`sensor_lock`)を取得——スケジュール測定とキャリブレーションのライブ表示(§12.2)が同時にセンサレール・UART・IMU・ADC を触らないための mutex
3. **IMU(LSM6DS3TR-C)**を起動して傾斜角 θ(光軸の真下からのずれ)・ピッチ(基板面内成分)・ロール(面外成分)と温度を取得し、IMU をパワーダウン(通電はレール投入前=LiDAR のピーク電流と重ねない)
4. **D10=SENSOR_EN を High** → 2SJ334 高側スイッチでセンサレール(VBAT_SW)通電、LDO・センサ安定待ち
5. **電池電圧 Vbat_start** を A0 分圧から取得(読み ×2)。**Vbat_start < 4.6V(TFmini 機)/ 3.8V(TSD20 機)なら LiDAR バーストをスキップ**(低電圧ガード: LDO が非レギュレーションに落ち、バーストでブラウンアウト→リセットループになるのを防ぐ。Vbat・傾斜・温度のみのレコードを残す)
6. UART 復帰(レール安定後。TSD20 機は「測距開始」コマンドを送る)、LiDAR から **N=100 フレーム(TFmini 100Hz 約 1 秒 / TSD20 200Hz 約 0.5 秒)**を受信 → 有効フレームの中央値・分散・強度中央値・チップ温度、n_frames / n_valid / n_out_of_range を算出(§3.3)
7. **Vbat_end** を負荷中に再取得(内部抵抗の指標)
8. UART 停止・TX を Hi-Z/Low → **SENSOR_EN Low** でレール遮断(幽霊給電対策)、ロック解放
9. レコード(§4.4)を QSPI フラッシュ(LittleFS)へ追記し、内部フラッシュのミラー領域へも書込。アドバタイズの死活情報(§12.2)を更新して System ON スリープへ復帰

実測: 1 サイクル **1.58 秒、ピーク 115〜117mA、0.037mAh**(§7.1)。

**リセット後のホールドオフ**: リセット直後は時計が最終レコードからの推定値になり(§4.6)、スケジューラが即座に発火し得る。ブラウンアウト→リセット→即測定→再ブラウンアウトのループを防ぐため、最初のスケジュール測定を **10 分 × 連続リセット回数(上限 12)** だけ遅らせる。連続リセット回数は settings(NVS、キー `sgd/boots`)で数える(v0.14 で GPREGRET2 から移行: **GPREGRET2 は WDT リセットで消える**ことを 2026-09-07 に実測。ソフトリセットのみ保持されるため、フォールト理由の受け渡しにだけ使う)。あらゆるリセット・電源断を跨いで残る。**連続 12 回**(`CONFIG_SNOWGAUGE_BOOT_MAX_RESETS`)に達するとその起動ではスケジュール測定を停止し(アドバタイズ・BLE は継続、フラグ MEAS_HALTED)、電池を守る。

**カウンタのクリア条件(v0.16 で変更)**: 従来は「起動から 10 分」というタイマーでクリアしていたが、それは最初のスケジュール測定より前に発火するため、**測定のたびにブラウンアウトする個体ではカウンタが貯まらず、停止機能が一度も働かない**(2026-09-11、レビューで判明)。v0.16 では次の 2 つでクリアする。

1. **センサレールに実負荷をかけた測定が完了し、レコードを保存できたとき**。測距値が有効かどうかは問わない(窓が雪で塞がれていても電池は耐えたことになる)。低電圧ガード(§4.3 の 4.6V/3.8V)でバーストを省略した測定は**負荷をかけていない**のでクリアしない。
2. **BLE 接続があったとき**(`diag_user_present()`)。スマホがつながる＝人が現地にいる＝そのリセット列は人為的な電源抜き差しであり、ブラウンアウトループではない。停止状態も解除し、ホールドオフの倍率を外して基本値(10 分)に戻す。

これは現地での実害への対処である: 設置時に電池ボックスの接触が悪くて入れ直すと、それだけでカウンタが上がり、最悪 12 回で測定停止に入る(2026-09-11 に PCB v1.2 のベンチで実際に発生し、定時測定が 1 回も走らなかった)。**設置手順として「最後に電源を入れてから最初の測定まで最大 10 分」「アプリを一度つなぐ」を必須にする**(`docs/02_assembly.md` C-2、`docs/04_app.md`)。なお v0.16 以降、**再起動だけでは停止状態から復帰しない**(クリア条件は上記 2 つのみ)。

### 4.4 データレコード(実装済み: 40 バイト固定・v1)

フィールド表の正は `docs/record_format.md`(実装は `firmware/src/record.h`)。概要:

| 内容 | フィールド |
|---|---|
| ヘッダ | magic `0x5347`("SG")、version=1、flags(TIME_SYNCED / TIME_ESTIMATED / LIDAR_OK / TILT_OK / MANUAL / FIRST_AFTER_BOOT / **SENSOR_TSD20**) |
| 時刻・通番 | epoch(UTC 秒、0=時計未設定)、seq(ERASE 以降の通番) |
| 測距 | dist_median_cm、dist_var_cm2、strength(中央値。TSD20 は 0)、n_frames、n_valid、n_out_of_range |
| 姿勢・温度 | tilt / pitch / roll(0.01°)、imu_temp(0.1℃、環境温度の代用)、lidar_temp(0.1℃、TFmini チップ温度。50〜75℃ が正常。TSD20 は -32768) |
| 電池 | vbat_start_mv(レール安定直後)、vbat_end_mv(センサ負荷中) |
| 整合性 | CRC-16(Zephyr `crc16_ccitt`、反転 CCITT、poly 0x8408、init 0xFFFF) |

積雪深はレコードに**格納しない**(§4.5 の式でオフライン算出。基準値 d0/θ0 は設定領域に持つ)。

**保存先**:
1. **主: QSPI 2MB 上の LittleFS**(`/lfs1`、nRF Connect Device Manager が固定で参照するパス)。**月ごとのファイル `/lfs1/rec_YYYYMM.bin`**(UTC 月)にレコードを連結追記。時計未設定の間は `/lfs1/rec_notime.bin`。8 回/日 で約 10kB/月、2 年で ≈250KB(QSPI の ~1/8)
2. **ミラー: 内部フラッシュの `mirror_partition`(0x9F000〜0xEC000、308kB ≈ 7,884 レコード ≈ 2.7 年分@8 回/日)**。追記専用の生スロット。リセット後の時計推定と通番の復元、シェルからの `rec dump`、QSPI 不調時のフォールバックに使う。満杯後は LittleFS のみに追記継続

**CSV 出力**(Web Bluetooth ページで生成。1 レコード 1 行、ヘッダ 1 行、UTF-8、`pandas.read_csv` 直読可。複数ロガーの連結のためサイト列は全行に繰り返す):

```
device_id, site_name, lat, lon, alt_m, tz_offset_min,
time_utc, time_local, seq, flags,
dist_cm, dist_var_cm2, strength, n_frames, n_valid, n_out_of_range,
tilt_deg, pitch_deg, roll_deg, imu_temp_c, lidar_temp_c,
vbat_start_mv, vbat_end_mv,
d0_cm, theta0_deg, snow_depth_cm
```

- `time_utc` は ISO 8601 UTC、`time_local` は機器設定 `sg/sched/tz_min` によるオフセット付き ISO 8601
- `flags` はフラグ名を `|` 連結
- 末尾 3 列は派生値: 機器に保存された基準 d0/θ0 と、§4.5 式による積雪深(基準または有効測距がなければ空)。生の `dist_cm` を残すので後から別基準で再計算可
- サイト列は `/lfs1/site.json`(§4.6)から。生の `.bin` もそのまま保存可能。オフライン復号は `tools/decode_records.py`

### 4.5 積雪深の算出

- 積雪深 = (無雪時基準斜距離 d0 − 現在斜距離 d) × cosθ
- θ は毎回の IMU 計測値(取付後の傾き事故検出を兼ねる)。**基板の取付姿勢(v0.15)**: 筐体内で基板を鉛直に立て、USB コネクタ左・センサ端子 J2 上・電池端子 J1 右・D0〜D6(TX)ピン列下(取付の作業性から 2026-09-11 に v0.14 の姿勢を面内 180° 回した)。この向きで光軸は IMU の **−Y**(この姿勢の加速度計の読みは a = (0, +1, 0) g。読みは上を向く軸に +1 g なので −Y が下向き)。θ = 重力と −Y のなす角、pitch = +X(面内、電池端子側)成分、roll = +Z(面外、部品面側)成分。ビルドオプション `SNOWGAUGE_SENSOR_AXIS`(`..._NEG_Y` が既定。旧姿勢は `..._POS_Y`、平置きのベンチ用は `overlay-flat.conf` で ±Z)。**定義と図の正は `docs/coordinate_system.md`**
- 基準 d0 は設置時に無雪面で ZERO を取るか、積雪面上で設置する場合はプローブで測った積雪深 h から d0 = d + h / cosθ として登録する(§12.2)

### 4.6 スケジュール・サイト情報・時計モデル(実装済み: `firmware/src/config.c`、`timekeeping.c`)

**スケジュール**(Zephyr settings に永続化、SMP settings group からページで読み書き):

| キー | 意味 |
|---|---|
| `sg/sched/start_min` | 測定窓の開始(現地時刻の分、0〜1439) |
| `sg/sched/end_min` | 測定窓の終了。start > end なら**日付をまたぐ**(例 17:00→05:00)、start == end なら終日 |
| `sg/sched/interval_min` | 測定間隔(分)。0 = スケジューラ停止 |
| `sg/sched/tz_min` | サイトの UTC オフセット(分、JST=540)。機器の時計は常に UTC で、窓の判定にのみ使う |

- 現在の運用値の例: 17:00〜05:00 / 90 分(夜間コア)。R2 の「日中もフラグ付きで測定」は終日設定で実現する
- **時計未設定時のフォールバック**: 時刻が一度も設定されていなくても、起動時刻を起点に `interval_min` ごとに測定し `rec_notime.bin` に記録する(欠測より相対時系列を優先)
- ベンチ用の `auto <秒>` シェルコマンドはスケジュールを上書きする

**サイト情報** = `/lfs1/site.json`。ページが fs upload で書く JSON(lat / lon / alt_m / accuracy_m / source=gps|manual / tz_min / tz_name / set_at / name / device_id / history[])。レコードには含めず、CSV 生成時に結合する。

**時計モデル**:
- nRF52840 にはカレンダー RTC がないため、32.768kHz 水晶で刻む**アップタイム基準の時計**(Zephyr rtc-emul を `rtc` エイリアスの背後に置き、mcumgr datetime 用にミラー)。状態は **UNSET / ESTIMATED / SYNCED** の 3 値
- リセットで時計は失われるので、起動時に**最新レコードの epoch から再シード**して ESTIMATED とする(以降のレコードは TIME_ESTIMATED フラグ: 単調だがオフセットあり)。巡回時にページの Sync で設定されると SYNCED になる(TIME_SYNCED フラグ)
- 設定を受け付ける時刻の妥当範囲は **2026〜2100 年**(範囲外は拒否)
- ドリフトは ~2.6 秒/日(rtc-emul)。巡回ごとの同期で吸収する。**時刻の定期退避(v0.14)**: 1 時間ごと(`CONFIG_SNOWGAUGE_TIME_SAVE_MIN`)と外部同期の直後に settings(NVS `sgt/epoch`)へ時刻を書き、起動時は「最終レコードの時刻」と「退避時刻」の遅い方を推定値にする。無記録期間が長くてもリセット後のずれは最大 1 時間 + 停止時間に収まる(書込は年 8,760 回、NVS のウェアレベリングで問題なし)

## 5. 空間代表性と設置プロトコル

樹幹取付は tree well(樹冠遮断+幹の長波放射で雪が少ない領域)の直上になりがちで、鉛直測定は系統的過小評価のリスク。

1. **斜め照準で tree well から脱出**: θ=20〜30° で幹から 2〜5m 離れた開けた雪面に照準(取付高 4m・θ25° → 幹から ~1.9m 先、斜距離 ~4.4m で R1 充足)
2. **設置プロトコル明文化**: 照準先の植生・微地形条件(下草・倒木・吹き溜まり回避)をチェックリスト化。設置時に BLE で照準先写真・初期値記録
3. **多点展開が本筋**: 森林内の空間相関距離は樹冠配置スケール(~10m 級)。1 サイト 3〜5 台 + カメラ雪尺で空間ばらつき自体をデータ化——業務機 1 台に対する差別化の中核

## 6. 主要コンポーネント(購入先リンク付き)

数量は PCB v1.2(`pcb/generate_board.py`)の部品参照に合わせた 1 台分。**発注用に集約した購入 BOM(数量・価格・購入先)は `docs/01_parts.md` を正とする**(本表は設計根拠の記録)。

| 部品 | 型番 | 数量 | 購入先 | 概算 | 備考 |
|---|---|---|---|---|---|
| MCU+IMU+温度 | **XIAO nRF52840 Sense**(A1) | 1 | [SwSci products/8146](https://www.switch-science.com/products/8146) | ~¥3,000 | LSM6DS3TR-C 内蔵(加速度+温度)。**予備を展開台数+2〜3 台確保**。基板に外付け I2C センサ用ヘッダ J3 を残しディスコンに備える。FW の IMU 層は抽象化 |
| LiDAR 廉価側(展開主力候補) | **PONO TSD20** | 1 | [秋月 131304](https://akizukidenshi.com/catalog/g/g131304/) | ¥2,580 | 8m@100kLux・3.3V 駆動・UART/I2C |
| LiDAR 上位側 | **Benewake TFmini Plus** | 1 | [SwSci products/8153](https://www.switch-science.com/products/8153) | ~¥7,000〜9,000 | IP65、強度+温度出力。A/B 比較用・FW 先行実装機 |
| 3.3V LDO(常時) | **NJU7223F33**(U1、TO-220F、C-MOS、500mA) | 1 | [秋月 100432](https://akizukidenshi.com/catalog/g/g100432/) | ¥80 | I_DD 30µA typ/60µA max、C-MOS で負荷比例のグラウンド電流なし。Vin 定格 14V |
| センサ用 LDO(測定時のみ) | U2: TSD20 機 **NJU7223F33** / TFmini 機 **NJU7223F50** | 1 | [F33: 秋月 100432](https://akizukidenshi.com/catalog/g/g100432/) / [F50: 秋月 100671](https://akizukidenshi.com/catalog/g/g100671/) | ¥50〜80 | 同一ピン配置(VOUT-VIN-GND)で基板共通、LDO 差し替えのみ。500mA でどちらのピークもカバー。5V 側代替: TA48M05F([秋月 100451](https://akizukidenshi.com/catalog/g/g100451/)) |
| 高側スイッチ | **2SJ334**(Q1、P-ch、TO-220、60V/30A、Ron ~70mΩ) | 1 | [秋月 102846](https://akizukidenshi.com/catalog/g/g102846/) | ¥110 | ピーク 500mA 時でも電圧損 ~35mV。ゲートは Vbat 振幅で完全 ON |
| ゲートドライバ | **2SK4017**(Q2、N-ch) | **1** | [秋月 107597](https://akizukidenshi.com/catalog/g/g107597/) | ¥30 | 2SJ334 のゲート駆動(GPIO 直結不可のため低側 1 石)。v1.2 で分圧側の Q3 を廃止し 1 個に |
| 逆接保護 | **1N5819**(D1、ショットキー 40V/1A) | 1 | [秋月 117244](https://akizukidenshi.com/catalog/g/g117244/) | ¥100/10本 | Vf ~0.35V@0.5A、スリープ µA 域では ~0.15V |
| パスコン | **0.1µF X7R 50V**(C1/C2/C3/C5) | **4** | [秋月 113582](https://akizukidenshi.com/catalog/g/g113582/) | ¥100/10個 | NJU7223 F33/F50 の入出力(C-MOS、0.1µF 指定) |
| 3.3V レール平滑 | **10µF**(C6、リード間隔 5mm) | 1 | 秋月 | — | XIAO 3V3 近傍。2.5mm ピッチ品は脚を広げて実装 |
| バルクコン | **OS-CON SEPC 470µF/16V**(C4、固体高分子、センサレール) | 1 | [秋月 108292](https://akizukidenshi.com/catalog/g/g108292/) | ~¥200 | ESR 10mΩ・リプル 6.1A・**-55℃対応で低温でも ESR 劣化なし**(アルミ電解は -20℃で ESR 数倍化)。リーク大きめだがゲート後なのでスリープ収支に無関係 |
| 抵抗(1/4W カーボン、-55℃対応) | **1MΩ ×2**(R1/R2 分圧)/ **10kΩ ×1**(R3 ゲート直列)/ **100kΩ ×2**(R4 Q2 プルダウン、R5 Q1 G-S プルアップ)/ **1kΩ ×1**(R7 TX 直列) | 6 | [1MΩ: 125105](https://akizukidenshi.com/catalog/g/g125105/)・[10kΩ: 125103](https://akizukidenshi.com/catalog/g/g125103/)・[1kΩ: 125102](https://akizukidenshi.com/catalog/g/g125102/)・100kΩ は同棚 | ¥120/100本 | 分圧は ±0.1V 精度で十分なのでカーボンで可(要精度なら金属皮膜へ)。v1.2 で R6 廃止 |
| 端子・ソケット | 5.08mm 2P ネジ端子(連結型)×3(J1 電池、J2 TFmini 4 連)、1×7 メス低背ヘッダ ×2(XIAO ソケット)、1×4 ピンヘッダ(J3、任意) | — | 秋月 | ~¥300 | 詳細は `pcb/README.md` |
| 基板 | SnowGauge PCB v1.2(64×50mm、2 層) | 1 | JLCPCB | — | `pcb/SnowGauge_v1.2_gerbers.zip`。M3 ×4 で固定 |
| 電池 | エナジャイザー L91 ×4 | 4 | — | — | ≈21Wh。低温特性・自己放電で最良 |
| その他 | 単3×4 ボックス、防水箱 | — | 秋月ほか | ~¥1,500 | 前プロトタイプ筐体: タカチ BCAP091208G |

**BOM 概算: TSD20 構成 ~¥8,000/台(電池・筐体込み、光学窓別)、TFmini Plus 構成 ~¥12,000〜14,000/台**(プランA ¥14,000 未満)。

## 7. 電力収支

### 7.1 精密見積り(予算)

- 電池: L91×4 ≈ 21Wh(≈3,500mAh) → 2 年で平均 200µA 以内が予算
- スリープ: LDO(NJU7223F33)30µA typ/60µA max + XIAO(System ON+RTC+BLE adv 1s)15〜25µA + IMU ~0.5µA ≈ **50µA typ / 90µA worst**
- 測定: TFmini 機 ~120mA / TSD20 機 ~50mA × 3 秒 × 8 回/日 → 日割り **~15〜35µA**(ワースト 5 秒で ~45µA)
- **合計典型 ~85µA → 4.7 年 ✓ / ワースト ~135µA → 2.9 年 ✓(マージン約 1.5 倍)**

#### 実測(ブレッドボード, 2026-09-03/04)

条件: `docs/breadboard_guide.html` の v1.2 同一トポロジ(抵抗は代替値)、ベンチ電源 6.00V を L91×4 の代わりに供給、INA228 電流計(picowatt、差分法、±10µA)。TFmini Plus 機、FW ステップ 3〜4b ビルド。詳細: `docs/measurements/2026-09-03_breadboard_current.md`。

| 項目 | 実測値 | 備考 |
|---|---|---|
| スリープ(システム全体、BLE なし) | **18µA ±10** | LDO Iq + XIAO + IMU パワーダウン + QSPI deep power-down + rtc-emul 1Hz。LittleFS 追加で変化なし |
| スリープ + BLE アドバタイズ 1〜2 秒 | **26µA ±10** | アドバタイズ増分 ≈ +8µA(2 秒固定なら約半分) |
| 測定バースト(IMU + TFmini 100 フレーム) | **1.58 秒、ピーク 115〜117mA、0.037mAh** | 8 回/日 → 0.30mAh/日 ≈ **3.5µA 平均** |
| **合計平均** | **≈30µA** | 予算 50µA typ / 90µA worst に対し十分な余裕 |
| **TSD20 機**: 測定バースト(IMU + TSD20 100 フレーム @200Hz) | **0.95 秒、通電中 42mA、突入 650mA/2ms、0.0098mAh** | 2026-09-07、U2=F33。8 回/日 → ≈ **0.9µA 平均**(TFmini 機の 1/4)。センサは通電後 150ms でストリーム開始 |
| **TSD20 機**: スリープ + BLE アドバタイズ | **36µA ±10** | 2026-09-07。TFmini 機のリリース FW(32µA、09-04)と誤差内で同じ → 合計 ≈37µA |
| (参考)USB を常時有効にした場合 | 1.89mA | Zephyr の USB デバイスが VBUS に関係なく HFXO+USBD を保持する罠。VBUS 検出時のみ有効化して解消 |

#### 実測(PCB v1.2, 2026-09-11) — 確定値

条件: **組み上げた PCB v1.2**、TFmini Plus 機、**使いかけの L91×4(無負荷 6.31V)**、picowatt(INA228、ADCRANGE=1、119Sa/s、`--cal` でゼロオフセットをサンプルごとに補正)。5 分間隔で 1 時間連続、測定 11 回。詳細: `docs/measurements/2026-09-11_pcb_v1.2_current.md`。

| 項目 | 実測値 | 備考 |
|---|---|---|
| スリープ + BLE アドバタイズ | **31.7µA**(統計誤差 0.2µA) | ブレッドボードの 32µA ±10 と一致。**基板化による増加なし** |
| BLE 接続中の増分 | **+100〜150µA** | 接続している間だけ。巡回は短く |
| 測定 1 回 | **37.23µAh、1.57 秒**(11 回で ±0.5%) | ピーク 328mA(470µF への突入)、プラトー 114mA |
| 測定中の電池電圧降下 | 6.31V → **5.34V** | 使いかけセル。即復帰 |
| **現地スケジュール(9 回/日)の平均** | **45.7µA = 1.096mAh/日** | スリープ 31.7µA + 測定 14µA 相当 |
| 期待電池寿命 | **≈7.5 年**(3,000mAh) | 自己放電・低温・末期容量は別途 |

ブレッドボードの差分法(±10µA)に対し、ゼロ補正込みで統計誤差 0.2µA。予算(典型 50µA / ワースト 90µA)に対して十分な余裕があり、**R3 の 2 年に対して余裕は 3 倍以上**。残る不確かさは低温特性(LDO の I_DD と電池容量)で、これは冬季試験で確認する。

**期待電池寿命(実測ベース)**: 3,500mAh ÷ 30µA ≈ 117,000 時間 ≈ 13 年(誤差上限 40µA でも ≈10 年)。ただし自己放電(L91 ~1 %/年 ≈ 4µA 相当)、低温での容量低下、4.6V ガードで使えない末期容量(1〜2 割)を差し引くと**実効 ≈8〜10 年**の見込み。いずれも R3(2 年)に対し十分な余裕で、実際の寿命は LDO の低温 I_DD と電池の低温特性で決まる。PCB v1.2 到着後に同条件で再測定して確定する(BLE 間隔・測定回数のノブは §7.2)。上記の予算値は引き続き設計上の上限として維持する。

### 7.2 運用方針

1. **NJU7223F33 を初号機から展開機まで共通採用**(v0.3 の「LP2950+低 Iq 差替の二段構え」は解消)。常温の I_DD・BLE 実電流は実測済み(§7.1)。低温特性(データシートは Tj=25℃ のみ)は PCB で追加実測
2. マージン追加が必要になった場合の調整ノブ: BLE アドバタイズ間隔 2〜4 秒化(数 µA 減)、夜間停止、測定回数削減。さらに欲しければ低 Iq 品(HT7533-1/MCP1702、Iq 2〜3µA)への差替オプションは温存(実測 30µA では不要の見込み)
3. 電池終盤は 5V LDO のドロップアウトで LiDAR 不可 → FW の**低電圧ガード(Vbat < 4.6V で LiDAR スキップ、Vbat・傾斜・温度のみ記録)**にフォールバックし、ログは最後まで継続(失う容量は末期 1〜2 割、マージン内)。§4.3

### 7.3 落とし穴チェックリスト

- [x] XIAO オンボード QSPI フラッシュの deep power-down(ドライバのランタイム PM で自動化。実測で増分なし)
- [x] IMU(LSM6DS3TR-C)のパワーダウン設定(読み出し時のみ通電)
- [x] USB デバイススタックを VBUS 検出時のみ有効化(入れ忘れは +1.9mA)
- [x] 常温の NJU7223F33 I_DD・BLE adv 実電流(§7.1)。低温は PCB で追加
- [x] 分圧抵抗の測定時のみ通電(VBAT_SW 給電で構造的に保証)
- [ ] TFmini Plus 低電力モード(85mW)の実挙動 → ピーク 500mA 問題が消える可能性(現状バースト平均 ~115mA で実用上問題なし)
- [x] TFmini Plus の UART ロジックレベル(3.3V LVTTL、直結で動作確認)。TSD20 は要実測(U12)

## 8. 誤差収支(積雪深)

| 誤差源 | 大きさ | 影響 | 対策 |
|---|---|---|---|
| LiDAR 測距 | ±5cm 級 | ±5cm | N 回 → 中央値 |
| 雪面反射(新雪/湿雪/クラスト) | 未知 | 欠測・異常値 | 強度・分散・番兵値頻度で品質フラグ、**初雪前に実測** |
| 環境光(晴天日中) | TFmini 70kLux 級で顕著の可能性 | 日中欠測 | 測定時刻の夜間配分、日中フラグ |
| IMU 個体オフセット | ±40mg(≈2°) | — | 設置時キャリブでゼロ点化、変化分運用 |
| IMU 温度ドリフト | ~±0.5mg/℃(40℃で ~1°) | θ=30° で ~1% | 温度毎回記録 → 事後回帰補正 |
| IMU 経年 | <0.5°/2 年 | <~0.5% | 巡回時再キャリブ |
| tree well バイアス | 系統(過小) | サイト依存 | 斜め照準プロトコル(§5) |

加速度計測は積分ドリフトなし(重力が絶対基準)。取付角 θ≦30°。

## 9. SWE への展望(次期)

二層アーキテクチャ構想:
1. **密な層**: SnowGauge 網(安価な深さ計)で空間パターンと時間変化を面的取得
2. **まばらな層**: SWE アンカー局で密度を地域較正。本命は **GNSS 屈折法**(雪面下埋設アンテナ+雪上参照、低コスト、乾湿両対応、SWE/深さ/LWC 同時導出)——同じ「安価モジュール+低電力 MCU」文化で兄弟機化可能
3. **モデル層**: 深さ時系列 → 密度モデル(Jonas 型・ΔSNOW 系)で SWE 推定(10〜15% 級)、アンカーで較正

参考: スノーピロー(高価・ブリッジング誤差)、γ線 GMON(SWE<600mm)、宇宙線中性子 CRNP(±15–30mm)、RFID 位相(湿雪弱)、24GHz FMCW(新興)。

## 10. 比較試験計画(2026-27 冬)

- 既存積雪深計サイト 3 箇所に併設、**4 系統クロスチェック**: TSD20 × TFmini Plus × 既製品(超音波)× カメラ雪尺(既存カメラ網+yamami)
- 狙い: 精度検証+方式×気象条件(降雪中・晴天・湿雪期)の失敗モード比較+「¥2,580 センサはどこまで戦えるか」を論文ネタ化
- 強度(TFmini)・分散・レンジ外頻度ログにより「いつ・なぜ測れなかったか」を定量化

## 11. 未決事項

| # | 項目 | 論点 | 期限感 |
|---|---|---|---|
| U1 | 名称 | SnowGauge 確定。商標・GitHub 衝突の形式確認のみ | 公開前 |
| U2 | 雪面での実効性能 | 新雪弱反射での測距成立性(TSD20/TFmini 両方、TSD10 で予備試験)。**初雪前が締切の最優先検証**。冷凍庫・人工雪で可 | 秋 |
| U4 | 電源部残件 | 常温は実測済み(§7.1)。残: NJU7223F33/F50 の低温 I_DD、5V レールのピーク垂下確認(OS-CON 470µF)、PCB v1.2 での再測定 | PCB 到着後 |
| U5 | 筐体・光学窓 | TFmini Plus は IP65 で大幅簡素化(フード+露出マウントも選択肢)。TSD20 側は透過窓(905nm ≧85%)+フード設計 | 秋 |
| ~~U6~~ | ~~BLE プロトコル~~ | **解決(v0.9、v0.12 実装完了)**: SMP(mcumgr)+カスタムキャリブサービス+アドバタイズ死活情報(§12) | — |
| ~~U7~~ | ~~FW 方針~~ | **解決(v0.9、v0.11 改、v0.12 実装完了)**: nRF Connect SDK(Zephyr)、書き込みは USB(UF2/シリアル DFU)。MCUboot/BLE DFU は将来展望(SWD プローブ要)。IMU 層抽象化(§12) | — |
| U8 | LPWA 拡張 | Wio E5 mini 接続・スリープ管理 | 次期 |
| U9 | 比較試験詳細 | 併設位置・雪尺設置・検証指標 | 2026-11 |
| U10 | 設置プロトコル文書 | 照準先チェックリスト・ページによるキャリブ手順(Sync → 照準 → ZERO/積雪深基準 → ダウンロード確認)。時刻同期手順自体はページで解決済み | 初回設置前 |
| U11 | SWE アンカー局 | GNSS 屈折法の実装調査 | 次期 |
| U12 | UART ロジックレベル | クローズ(2026-09-07): TFmini・TSD20 とも 3.3V で直結動作確認済み | — |
| U13 | WDT | **実装(v0.14、2026-09-07)**: ハードウェア WDT 120 秒 + 監視ワーク(§12.4)。Adafruit ブートローダは 0.6.1 以降 DFU 待ちループで走行中の WDT を給餌する(`bootloader.c` `wait_for_events()`)ため `dfu` 経路は成立。実機検証済み(2026-09-07): `dfu`→書込→起動、`hang`/`fault`/`panic`/`stall` の再起動と boot.log、スリープ電流 22µA±10(増加なし、`docs/measurements/2026-09-07_wdt_breadboard_current.md`)。時刻の定期退避(§4.6)は別途 | クローズ |
| U14 | TSD20 FW 変種 | **実装・実機検証済み(v0.13、2026-09-07)**: `lidar.h` 抽象化 + `tsd20.c`(4B フレーム、番兵 50000mm、460800 baud、測距開始コマンド)、`overlay-tsd20.conf`、`docs/breadboard_guide_tsd20.html`。ブレッドボード(U2=F33)で 100 フレーム/499ms・チェックサムエラー 0 を確認。残: 電流プロファイル・第 2 リリース資産 | 2026-09 |
| U15 | BLE アクセス制御 | ペアリングなしのため近傍の第三者が設定変更・消去できる。ERASE はダウンロード後のみ受付+トークンで緩和。必要なら PIN を追加 | 展開前に判断 |

(旧 U3=加速度センサは Sense 内蔵 IMU 採用によりクローズ)

## 12. ファームウェア・BLE 設計(v0.9 確定、v0.12 実装反映)

### 12.1 フレームワークと書き込み(旧 U7)

- **nRF Connect SDK(Zephyr)v3.4.0** に固定。ボード `xiao_ble/nrf52840/sense`。ソースは `firmware/`(モジュール一覧は `firmware/README.md`)
- **書き込みは USB のみ、MCUboot なし**: XIAO 出荷時の Adafruit UF2 ブートローダを温存し、アプリを 0x27000 以降に配置する。ダブルタップリセットで現れる `XIAO-SENSE` ドライブへ `zephyr.uf2` をコピーするか、UF2 ドライブをマウントできない環境(macOS 26)では `adafruit-nrfutil dfu serial` によるシリアル DFU(シェルの `dfu` コマンドでブートローダへ遷移)で書き込む
- **MCUboot / BLE DFU は将来展望**: 0x0 のブートローダを上書きするため裏面 SWD パッドからのプローブ書き込みが必要。現地の FW 更新は筐体開放・電池切離し・USB 接続で行う(基板シルクの「NO USB WHILE BATTERY CONNECTED!」)
- **配布**: ビルド済み FW は GitHub Releases で配布する(初回タグ `fw-2026-09-04`、UF2 とシリアル DFU パッケージ)。TSD20 機用は同じタグに `_tsd20` 付きの第 2 資産(`overlay-tsd20.conf` ビルド)として置く
- **センサ変種**: Kconfig choice `SNOWGAUGE_SENSOR`(TFMINI 既定 / TSD20)。共通層 `lidar.c`(UART 受信・N 標本統計)の下に `tfmini.c` / `tsd20.c`。ボーレートは起動時に `uart_configure()` で変種の値に切替。シェルは `lidar read|raw|rate|save|info`(旧 `tfmini` は別名として残す)
- **IMU 層抽象化**: `TiltSensor` インターフェイス(init/read_tilt/read_temp/power_down)の下に LSM6DS3TR-C 実装。ディスコン時は J3 の外付け I2C センサ実装を追加するのみ
- 内部フラッシュ 1MB のレイアウト: Adafruit ブートローダ/SoftDevice 領域(0x0〜0x27000、156kB)+ アプリ(0x27000〜、480kB)+ **レコードミラー `mirror_partition`(0x9F000〜、308kB)** + settings 領域(0xEC000〜、32kB: スケジュール・キャリブ)+ ブートローダ用 UF2 領域(0xF4000〜、48kB)。レコード本体は QSPI 2MB(LittleFS、§4.4)

### 12.2 BLE プロトコル(旧 U6)

3 層構成。**現地 UI は Web Bluetooth ページ**(§12.3)で、nRF Connect Device Manager は echo・ファイルダウンロードのみのフォールバック。

1. **アドバタイズ死活情報(接続レス巡回チェック)** — `firmware/src/ble_adv.c`
   - 接続可能アドバタイズ、間隔 1〜2 秒(電力ノブ、§7.2)、デバイス名 `SG-TFM-XXXX` / `SG-TSD-XXXX`(センサ種別 + デバイス ID 下位 2 バイト。v0.13 で種別を追加、旧 FW は `SG-XXXX`)はスキャンレスポンスに載せる
   - Manufacturer Data(company ID 0xFFFF=未割当/試験用)18 バイト: payload version(2)/ 最終レコードの vbat_end_mv / レコード数 / 最終測距中央値(cm、0xFFFF=無効)/ 状態フラグ(TIME_SYNCED、TIME_ESTIMATED、LAST_LIDAR_OK、FS_OK、MIRROR_FULL、LAST_MEAS_ERR、**ABNORMAL_RESET、MEAS_HALTED**)/ 最終レコードの epoch / 稼働時間(時間、飽和)/ **連続リセット回数 / 最終リセット理由**(v0.14 追加、`ble_adv.h`)
   - 巡回時はスキャンのみで死活・概況確認が完了(任意のスキャナで可)
2. **SMP over BLE(mcumgr)— 標準機能をそのまま使う** — `firmware/src/smp_mgmt.c`
   - os mgmt: echo(死活)、**datetime get/set(時刻同期、フックでアプリ時計を SYNCED に)**、reset
   - fs mgmt: `/lfs1/rec_*.bin` の**ダウンロード**、`/lfs1/site.json` の**アップロード**
   - settings mgmt: `sg/sched/*`(§4.6)の読み書き
   - img mgmt(DFU)は非搭載(§12.1)。SMP は USB シェルポート上でも使える(ベンチ用 `tools/smp_datetime.py`)
3. **カスタムキャリブレーションサービス(自前 GATT)** — `firmware/src/cal_gatt.c`
   - Service UUID `53470001-6E63-4D61-8B0C-7A8E9F0B1C2D`
   - **live**(`53470002-…`、notify、12B、約 250ms 周期): dist_cm / strength / tilt(0.01°)/ vbat_mv / n_valid / n_frames / var_cm2。照準先確認用。センサレールを通電したまま(~120mA)なのでページが必ず停止し、5 分でタイムアウトもする
   - **control**(`53470003-…`、write): `0x00` live 停止 / `0x01` live 開始 / `0x10` **ZERO**(無雪: d0 = 測距値)/ `0x11` + u16 積雪深 cm(**プローブ積雪深からの基準**: d0 = d + h / cosθ)/ `0x20` + `"ERASE"`(全レコード消去)。ZERO 系は 1 回分の完全測定を行い、レコードも残す。d0・θ0・取得時刻は `sg/cal/*` に永続化
   - **status**(`53470004-…`、read、12B): d0_cm / theta0(0.01°)/ set_epoch / live / last_cmd_result / **busy / cmd_seq**。コマンドは専用ワークキューで実行し、ページは busy==0 かつ cmd_seq 一致までポーリングして結果を読む。busy 中の書込は拒否

### 12.3 現地 UI: Web Bluetooth ページ

- **https://0kam.github.io/SnowGauge/app/**(`docs/app/`、GitHub Pages)。Android Chrome / PC Chrome(Windows・macOS・Linux)で動作。iPhone は Safari 非対応のため Bluefy 等の Web Bluetooth ブラウザを使う
- **PWA・オフラインファースト**: 一度開けばサービスワーカーがキャッシュし、電波のない現地でも起動する
- SMP を JS で実装(`cbor.js`・`smp.js` は汎用、`app.js` にレコード/設定スキーマとキャリブパネル)。他ロガーへの流用はスキーマとパネルの差し替えのみ
- 機能: **Sync**(時刻+タイムゾーン+位置情報を一括送信。tz はスマホから自動)、スケジュール設定、レコードのダウンロード(CSV + 生 .bin、§4.4)、ライブ照準表示、ZERO / 積雪深基準登録、ERASE
- **UI ルール(手袋・小画面前提)**: 大きなボタン、数値入力はピッカーのみ(手動 lat/lon を除く)、ページ/機器が決める値の UI は出さない(tz 自動、d0/θ0 は表示のみ)、**破壊的操作は 2 タップ**(1.5 秒以上の間隔)
- 2026-09-04 に Android 実機で全機能(Sync・設定・ライブ・ZERO/基準・ダウンロード/CSV・消去)を検証済み

### 12.4 堅牢化(2026-09-04 独立レビュー反映)

- **センサ排他ロック**: スケジュール測定とライブ表示がレール・UART・IMU・ADC を同時に触らない(§4.3)
- **低電圧ガード**: Vbat < 4.6V で LiDAR バーストをスキップ(§4.3、§7.2)
- **ブートホールドオフ**: リセット直後の最初の測定を 10 分 × 連続リセット回数だけ遅延(NVS で計数、§4.3)
- **ERASE の条件付け**: 起動後にレコードファイルが SMP で読まれる(=ダウンロード済み)まで BLE からの ERASE を拒否(レコードなしなら可)。トークン `"ERASE"` 必須
- **2 タップ確認**: ページの破壊的操作(ZERO・基準設定・ERASE・未同期での切断)は 2 タップ、その間すべてのボタンをロック
- **要求の直列化**: ページは SMP 要求を 1 本ずつ送り、タイムアウト時は受信バッファを破棄。キャリブコマンドは機器側ワークキュー+busy/seq で直列化
- ライブ表示は ZERO 後も接続中のみ再開、切断でレールを落とす
- 時刻設定は 2026〜2100 年のみ受付、設定値は検証してからコミット
- **WDT + 監視(v0.14)**: nRF52 ハードウェア WDT(120 秒、スリープ中も動作、`firmware/src/wdt_mon.c`)。システムワークキュー上の監視ワークが 30 秒ごとに「スケジューラループが 2 時間以内に 1 周した」「進行中の測定が 60 秒以内」「アドバタイズ中または接続中(意図的な停止を除く)」を確認し、全部満たすときだけ給餌する。どれかが固まればワークキューや CPU が生きていても WDT リセットに至る
- **フォールト時再起動(v0.14)**: 例外・スタック溢れ・`k_panic` は Zephyr 既定の停止ではなく、理由コードを GPREGRET2 に残して再起動する(`firmware/src/diag.c`)。実機確認済み(2026-09-07): `fault`→`fatal=cpu-exception`、`panic`→`fatal=panic`、`hang`/`wdt stall`→`cause=watchdog`(停止から約 95〜140 秒)、WDT 走行中の `dfu`→シリアル DFU→起動も成立
- **リセット理由の記録(v0.14)**: 起動時に RESETREAS(hwinfo)を読んでクリアし、`/lfs1/boot.log` に 1 行追記(時刻・連続回数・理由・フォールト種別・FW 変種、8kB でローテート、ERASE で削除)。シェル `diag [log]`、アドバタイズにも回数と理由を載せる
- **検証コマンド(v0.14)**: `hang`(割込禁止で無限ループ → WDT)、`fault`(未定義命令 → 例外)、`panic`、`wdt stall <ch>`(監視経路のみを試す)
- **センサ無応答リトライ(v0.14)**: バーストで 1 フレームも得られなければレールを 1 秒落として 1 回だけやり直す(TSD20 は stop を明示送信してから遮断、再投入で start)。レコードにフラグ RETRIED(bit 7)。TFmini・TSD20 の両ブレッドボードで実機確認済み(2026-09-07、誤ボーレートで無応答にして経路を実行、TSD20 は stop→start 後も正常測距)
- **時刻の定期退避(v0.14)**: §4.6
- 保留: `site.json` の書き込み途中断(lat/lon を settings にも持つ)、ミラー消去失敗時の扱い、即時再接続の再試行、ライブ中に到来したスロットの扱い、tz 変更の確認ダイアログ

### 12.5 FW 必須要件(既出の再掲)

- 遮断前に UART TX を Hi-Z/Low 化(幽霊給電対策、§4.3)—— 実装済み。ランタイム PM のデフォルト有効化は UARTE がレール OFF 中に TX を High へ戻すため無効にしている
- QSPI フラッシュ deep power-down、IMU パワーダウン(§7.3)—— 実装・実測済み
- レコードの内部フラッシュミラー(§4.4)—— 実装済み
- WDT 有効化 —— 実装済み(v0.14、実機検証待ち、U13)

## 13. マイルストーン

- 2026-08-16〜17: 仕様 v0.1〜v0.8(方式・部品確定)
- 2026-09-02: PCB v1.2 発注(JLCPCB)、ブレッドボード開発環境整備、FW ステップ 1(Zephyr 基盤・TFmini UART)
- 2026-09-03: ブレッドボード完成(STEP 1〜5 検証)、FW ステップ 2〜3(測定シーケンス、スリープ電流 17〜18µA)、ステップ 4a〜4b(レコード保存・アドバタイズ、26µA)
- 2026-09-04: FW ステップ 4c〜4d(SMP・キャリブ GATT)、Web Bluetooth ページ公開・Android 実機検証、独立レビューによる堅牢化(§12.4)、FW 初回リリース `fw-2026-09-04`、リリース FW のスリープ電流 32µA、FW ステップ 5(TSD20 変種)実装・両変種ビルド通過
- 2026-09-07: TSD20 変種のブレッドボード実機検証(U14)、リリース `fw-2026-09-07`、WDT・フォールト再起動・リセット理由記録(U13、§12.4)実装
- **次**: WDT 実機検証(dfu 経路・hang/fault・スリープ電流)/ PCB v1.2 到着(~2026-09-10)→ 実装・全項目再測定(U4)/ 学生組立会(2026-09-17、ブレッドボードガイド+ページ使用手順)/ U2 反射検証
- 2026-11: 比較試験詳細確定、展開機製作
- 2026-12-31: 比較試験開始(既存 3 サイト併設)

## 14. 改版履歴

| 版 | 日付 | 内容 |
|----|---|---|
| v0.1 | 2026-08-16 | 初版。基本アーキテクチャ決定 |
| v0.11 | 2026-09-02 | **MCUboot / BLE DFU を将来展望に降格、書き込みは USB(UF2)のみ**(SWD プローブ不所持、SWD パッド作業の負荷を考慮)。FW ステップ 1 完了: NCS v3.4.0、`firmware/` にセンサレール制御・TFmini ドライバ・電池 ADC・USB シェルを実装(実機検証はブレッドボード完成後)。内部フラッシュは Zephyr `xiao_ble` 標準レイアウト |
| v0.12 | 2026-09-04 | 実装反映版。§3.2 を TFmini Plus vs TSD20 の A/B に更新(TSD10 は経緯のみ)、§3.3 番号修正。§4.3 を実装シーケンス(IMU→レール→Vbat→N=100@100Hz→Vbat→遮断、低電圧ガード 4.6V、センサ排他、ブートホールドオフ)に更新。§4.4 を 40B レコード v1・月次ファイル・内部ミラー 308kB・CSV 列定義に更新。**§4.6 新設**(スケジュール/サイト情報/時計モデル)。§6 BOM を PCB v1.2 数量に修正(2SK4017 ×1、100kΩ ×2、0.1µF ×4+C6、Q3/R6/D3 なし、TSD10 行削除、購入 BOM は `docs/01_parts.md`)。**§7.1 に実測を追加**(スリープ 18µA、adv 込み 26µA、バースト 0.037mAh、合計 ≈30µA → 電池寿命 実効 ≈8〜10 年)。§12 を実装内容(NCS v3.4.0、UF2/シリアル DFU、アドバタイズペイロード、SMP 3 グループ、キャリブ GATT の UUID・コマンド、**Web Bluetooth ページを現地 UI に**、堅牢化、GitHub Releases `fw-2026-09-04`)に書換。§11 U6/U7 クローズ維持・時刻同期手順解決、U13 WDT・U14 TSD20 変種・U15 アクセス制御を追加。§13 に 09-02〜04 の実績と次工程。全体で D10=SENSOR_EN・A0 分圧は VBAT_SW・D3 廃止に統一 |
| v0.13 | 2026-09-04 | **TSD20 FW 変種(U14)実装**: §3.2 に実装形態(`lidar.h` 抽象化、`overlay-tsd20.conf`、BLE 名 `ST-`、flags bit 6)、ボーレートは既定 460800 で実装。§3.3 に TSD20 の mm→cm 丸めと strength/lidar_temp の扱い。§4.3 低電圧ガードを変種別(4.6V / 3.8V)に。§4.4 に SENSOR_TSD20 フラグ。§11 U12 を説明書値(3.3V)に更新、U14 を実装済み(残: 実機検証)に。§12.1 に第 2 リリース資産とセンサ変種の構成。§13 に 09-04 の追記。ブレッドボードガイドに TSD20 版(`breadboard_guide_tsd20.html`)と組み替え手順 §5 を追加。09-07 追記: TSD20 版ブレッドボード実機検証(U12/U14)、§7.1 に TSD20 機の実測(バースト 0.0098mAh、スリープ 36µA)、BLE 名を `SG-TFM-XXXX` / `SG-TSD-XXXX` に変更 |
| v0.14 | 2026-09-07 | **基板鉛直取付に伴う傾斜軸の変更**(§4.3/§4.5: 光軸 = IMU +Y、pitch/roll を面内・面外成分に再定義、`overlay-flat.conf`)。**WDT・堅牢化(U13)**: センサ無応答リトライ(§12.4、レコード flag bit 7 RETRIED)と時刻の定期退避(§4.6、NVS `sgt/epoch`)を追加。 §4.3 ホールドオフに連続 12 回で測定停止を追加、§11 U13 を実装済み(実機検証待ち)に、§12.2 アドバタイズペイロードを v2(18B、ABNORMAL_RESET/MEAS_HALTED フラグ、連続リセット回数、リセット理由)に、§12.4 に WDT 監視・フォールト時再起動・boot.log・検証コマンドを追加、§12.5 更新、§13 に 09-07 の実績 |
| v0.15 | 2026-09-11 | **取付姿勢を面内 180° 変更**(取付の作業性: USB コネクタ左・センサ端子 J2 上)。§4.5 の光軸を IMU **−Y** に、pitch の +X を電池端子側に読み替え(pitch/roll の定義そのものは不変)。Kconfig `SNOWGAUGE_SENSOR_AXIS` に `NEG_Y`(既定)を追加し `POS_Y` は旧姿勢用として残置。`docs/coordinate_system.md` の図を再生成(生成スクリプト `docs/assets/figures/gen_coordinate_system.py` を新設)、§4.5・02_assembly.md C-2・record_format.md・05_data.md を更新 |
| v0.16 | 2026-09-11 | **PCB v1.2 の電流実測を確定**(§7.1: スリープ 31.7µA、測定 37.23µAh/回、現地 9 回/日で平均 45.7µA → 約 7.5 年。基板化による増加なし)。**リセットバックオフの修正**(§4.3: カウンタのクリアを「起動 10 分」タイマーから「実負荷をかけた測定の保存成功」と「BLE 接続」に変更。従来はタイマーが最初の測定より先に発火するため停止機能が働かなかった。BLE 接続で停止解除＝人為的な電源抜き差しの救済)。設置手順に「最後の電源投入から最初の測定まで最大 10 分」「アプリを一度つなぐ」を追加(02_assembly.md C-2、04_app.md)。リリース `fw-2026-09-11` |
| v0.2 | 2026-08-17 | 名称確定、測距方式ゼロベース検討、波長要件、空間代表性、SWE 構想、比較試験 3 系統化 |
| v0.3 | 2026-08-17 | LiDAR 再選定(TFmini Plus 本命、TSD10 と A/B)。TSD10 データシート精査反映(電流 4mA・環境光 2m@100kLux・測定時刻の夜間配分)。動作温度要件を -20℃ に変更。電源系全面再設計(昇圧廃止、遮断側 5V LDO、LP2950+低 Iq 差替の二段構え、電力収支精密化: 典型 3.0 年/ワースト 2.1 年)。MCU を Sense に変更(内蔵 IMU+温度、ディスコン対策は予備確保+基板パッド)。全主要部品に購入先リンク付与。改版ポリシー(全文改版)を明記 |
| v0.4 | 2026-08-17 | 3.3V LDO を **NJU7223F33**(秋月 100432、TO-220F、C-MOS、I_DD 30µA typ/60µA max)に確定。LP2950 と低 Iq 差替の二段構えを廃止し全機共通化。電力収支更新: **典型 ~85µA → 4.7 年 / ワースト ~135µA → 2.9 年**。残実測: I_DD 低温特性(データシートは Tj=25℃ のみ) |
| v0.5 | 2026-08-17 | 5V LDO を **NJU7223F50**(秋月 100671、¥50、TO-220F、500mA)に確定——3.3V 側と同一ファミリで統一、通電中自己消費も 13mA(TA48M05F)→30µA に改善。電源系全部品が秋月+スルーホールで確定完了 |
| v0.6 | 2026-08-17 | 高側スイッチを PNP 案から **2SJ334**(P-ch、電圧損 ~35mV@500mA)+**2SK4017** ドライバに変更・確定。逆接保護 **1N5819**、パスコン **0.1µF X7R**、バルク 470µF、分圧 1MΩ×2+低側 SW を確定。**全部品確定、発注可能** |
| v0.7 | 2026-08-17 | バルクコンを **OS-CON SEPC 470µF/16V**(秋月 108292)に確定——固体高分子で低温 ESR 劣化なし(-55℃対応)、厳冬期のピーク吸収性能を保証。抵抗類の型番・リンク確定(1/4W カーボン、-55℃対応)。部品表は全行リンク付きで発注リストとして完結 |
| v0.8 | 2026-08-17 | 廉価側 LiDAR を **TSD20**(秋月 131304、¥2,580)に交代——耐環境光 8m@100kLux(日中測定可)・10m@10% 反射率・**3.3V 駆動**・905nm 明記・UART/I2C。センサレールを LDO 差し替え式に統一(F33=TSD20 機/F50=TFmini 機、同一ピン配置で基板共通)。TSD20 機は Vbat ~3.8V まで LiDAR 稼働(電池ほぼ全容量)。UART 直結確認(変換ボード不要)と幽霊給電対策(遮断前 TX Hi-Z 化)を FW 必須要件化。レンジ外番兵値の差(TSD20: 50000/TSD10: 65535)を明記。TSD10 はベンチ試験係へ |
| v0.10 | 2026-09-02 | PCB v1.2 確定・発注(JLCPCB、64×50mm、穴57×43mm)。**電池監視を VBAT_SW からの分圧に変更**(Q3/R6/GPIO D3 廃止。nRF52840 の絶対最大定格違反を独立検証で検出し修正)。SENSOR_EN は **D10**(基板引き回し都合で D2 から変更)。端子は 5.08mm 2P 連結×3(J1電池/J2 TFmini 4連)。正のピンマップは pcb/README.md。ブレッドボード開発環境(docs/breadboard_guide.html、同一トポロジ)整備 |
| v0.9 | 2026-09-02 | U6・U7 クローズ(§12 新設)。FW 基盤を **nRF Connect SDK(Zephyr)+MCUboot** に確定、**BLE DFU を v1 搭載**。BLE は SMP(mcumgr: DFU/ファイル吸い出し/時刻同期)+カスタムキャリブサービス+アドバタイズ死活情報の 3 層構成。スマホは nRF Connect Device Manager(iOS/Android)で専用アプリ不要。開発順: TFmini Plus 機を先行、配線確定→組立説明書→FW 並行開発 |

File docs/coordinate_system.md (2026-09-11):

# 座標系と傾斜の定義（基板の取付姿勢、IMU 軸、tilt / pitch / roll）

2026-09-11 に取付姿勢を 180° 回して「USB 左・センサ端子 J2 上」にしました（それ以前は USB 右・J2 下）。
光軸は IMU の **−Y** です。この文書が傾斜まわりの定義の正です。他の文書はここへリンクします。

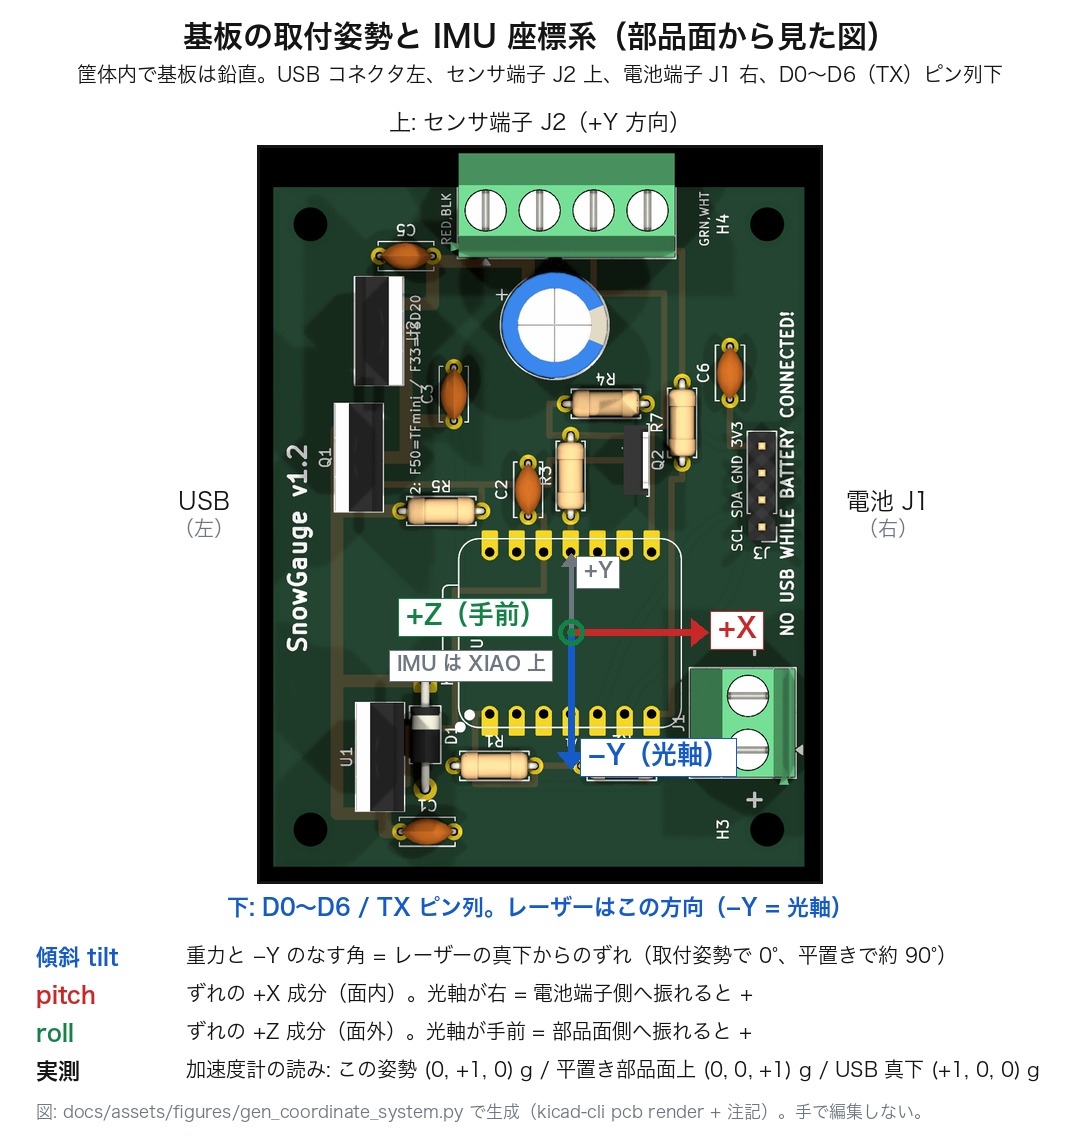
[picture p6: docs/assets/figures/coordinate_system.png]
基板の取付姿勢と IMU 座標系


（図: `docs/assets/figures/gen_coordinate_system.py` で生成。`kicad-cli pcb render` の上面図を反時計回りに 90° 回し、軸と文字を描き足したもの。基板や取付姿勢を変えたら再実行する。手で編集しない）

## 1. 取付姿勢

筐体の中で PCB v1.2 は**鉛直**に立てます。部品面から見て:

| 辺 | あるもの |
|---|---|
| 上 | センサ端子 J2（TFmini / TSD20）。センサのケーブルは筐体内を上へ回して J2 に入れる |
| 左 | XIAO の USB コネクタ |
| 下 | XIAO の D0〜D6（TX）ピン列、リセットボタン側。**レーザーはこの向き（真下）に出る** |
| 右 | 電池端子 J1 |

これは `pcb/README.md` の基板上面図（USB が上辺）を**反時計回りに 90°** 回した向きです。
センサ本体は筐体の外に真下向きで固定します。基板のどの辺に J2 があるかとレーザーの向きは無関係で、
傾斜の基準になるのは「基板に対してセンサがどちらを向いているか」です。

## 2. IMU の座標系（XIAO nRF52840 Sense の LSM6DS3TR-C）

取付姿勢で見たときの軸の向き（2026-09-07 に 3 姿勢で実測、2026-09-11 の姿勢変更で符号を付け替え）:

| 軸 | 向き | 根拠となる読み |
|---|---|---|
| **−Y** | **下 = レーザー光軸** | 取付姿勢で a = (0, +1, 0) g |
| +X | 右（電池端子側、USB と反対） | USB を真下にすると a = (+1, 0, 0) g |
| +Z | 手前（部品面側の法線） | 平置き部品面上で a = (0, 0, +1) g |

加速度計は静止時に**上を向いた軸に +1 g** を出します（重力の反作用）。したがって「−Y が下向き」は「ay = +1 g」として観測されます。ファームウェアの符号はこれに合わせてあります（`firmware/src/tilt_lsm6dsl.c`）。
この姿勢では +X 右・+Y 上・+Z 手前で、図の見た目どおりの右手系になります。

## 3. 傾斜量の定義（レコードとアプリで使う値）

すべて 0.01° 単位の符号付き 16 bit でレコードに入ります（[record_format.md](record_format.md)）。

| 値 | 定義 | 取付姿勢での目安 |
|---|---|---|
| `tilt` | 重力方向と光軸（−Y）のなす角。**レーザーの真下からのずれ** | 0°（傾けた分だけ増える。平置きでは約 90°） |
| `pitch` | ずれの **+X 成分**（基板面内）。光軸が右 = 電池端子側へ振れると + | 0° |
| `roll` | ずれの **+Z 成分**（基板面外）。光軸が手前 = 部品面側へ振れると + | 0° |

計算: `tilt = acos(ay / |a|)`、`pitch = atan2(ax, ay)`、`roll = atan2(az, ay)`。

積雪深の式で使うのは `tilt` だけです: `積雪深 = (d0 − d) × cos(tilt)`（仕様書 §4.5）。`pitch` / `roll` は「どちらへ傾いたか」を知るためのもので、設置時の照準調整と、設置後にポールが動いたときの向きの判定に使います。

## 4. 現地で見えるもの

- アプリのライブ表示「傾斜 °」= `tilt`。斜め照準（θ = 20〜30°）なら 20〜30 が出ているのが正常。
- シェル `tilt` は `tilt=… from nadir (axis -Y)  pitch=… (toward +X)  roll=… (toward +Z)  a=(ax,ay,az) mg` を出す。`a` の読みが §2 の表と合っていれば軸の解釈は正しい（取付姿勢で ay ≒ +1000 mg）。
- 基準傾斜 θ0（ZERO を取ったときの `tilt`）は設定に保存され、アプリで表示のみ。

## 5. ベンチ（平置きのブレッドボード）での注意

既定ビルドは鉛直取付用なので、平置きでは `tilt` が約 90° と出ます。平置きで 0° を出したいときは `overlay-flat.conf` を付けてビルドします（光軸 = ±Z、どちらの面が上でも可）。ビルドオプションは Kconfig の `SNOWGAUGE_SENSOR_AXIS`（`firmware/README.md`）。

基板を上下逆さ（USB 右・J2 下）に立てると `tilt` は 180° と出ます。0° に近い値が出ない、
あるいは ay が −1000 mg 付近なら取付の向きが逆です。

## 6. 以前のファームウェアとの違い

| | 2026-09-07 より前 | 2026-09-07〜09-11 | 以後（既定） |
|---|---|---|---|
| 取付姿勢 | 平置き | 鉛直・USB 右・J2 下 | 鉛直・USB 左・J2 上 |
| 光軸 | 基板法線（±Z） | +Y | **−Y** |
| `tilt` | 重力と法線のなす角 | 重力と +Y のなす角 | 重力と −Y のなす角 |
| `pitch` | X 軸の水平面からの角度 | ずれの +X 成分 | ずれの +X 成分（同じ） |
| `roll` | Y 軸の水平面からの角度 | ずれの +Z 成分 | ずれの +Z 成分（同じ） |
| Kconfig | `..._AXIS_Z` | `..._AXIS_POS_Y` | `..._AXIS_NEG_Y` |

`pitch` / `roll` の定義（面内 +X 成分・面外 +Z 成分）は変わっていません。基板面内で 180° 回したため、
`pitch` の +X 側だけが**現場では左から右へ反転**します（電池端子側のまま）。
`roll` の +Z 側（部品面側の法線）は変わりません。
古いファームウェアで取ったレコード（試験データのみ。展開機はすべて新定義）は旧定義の値です。
レコード形式（version 1）は変えていないので、どちらの定義で取られたかはファームウェアの日付で判断します。

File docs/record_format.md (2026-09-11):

# SnowGauge record format (v1) and storage layout

Source of truth: `firmware/src/record.h` (layout), `firmware/src/storage.h`
(where records live). Decoder: `tools/decode_records.py`.

## One record = 40 bytes, little-endian

| off | size | field | unit / meaning |
|---:|---:|---|---|
| 0 | 2 | magic | `0x5347` (`"SG"` as bytes) |
| 2 | 1 | version | 1 |
| 3 | 1 | flags | see below |
| 4 | 4 | epoch | UTC seconds; 0 = clock was unset |
| 8 | 4 | seq | record counter since the last ERASE |
| 12 | 2 | dist_median_cm | median of valid LiDAR samples (TSD20: mm rounded to cm); 65535 = none valid |
| 14 | 2 | dist_var_cm2 | variance (clamped to 65535); 65535 = none valid |
| 16 | 2 | strength | TFmini signal-strength median; **0 on the TSD20** (no strength output) |
| 18 | 2 | n_frames | checksum-good frames in the burst (N=100 nominal) |
| 20 | 2 | n_valid | frames used for the distance statistics |
| 22 | 2 | n_out_of_range | sentinel (TFmini 0/65535 cm, TSD20 50000 mm) + saturated + weak-signal frames |
| 24 | 2 | tilt | 0.01°, angle between gravity and the LiDAR optical axis (deviation from nadir; definitions and figure: [coordinate_system.md](coordinate_system.md)); -32768 = IMU failed. Optical axis in the IMU frame = build option `SNOWGAUGE_SENSOR_AXIS`: **−Y** for the vertical PCB in the enclosure (USB left, sensor terminal J2 up; firmware from 2026-09-11 on), +Y for the 2026-09-07…09-11 mount (USB right), ±Z (board normal) for a flat board and for all earlier firmware |
| 26 | 2 | pitch | 0.01°, signed component of the deviation toward IMU +X (in the PCB plane, toward the USB side) |
| 28 | 2 | roll | 0.01°, signed component toward IMU +Z (out of the PCB plane, component side) in the ±Y builds; toward +Y in the Z build |
| 30 | 2 | imu_temp | 0.1 °C, signed (environment proxy) |
| 32 | 2 | lidar_temp | 0.1 °C, signed; TFmini *chip* temperature (50–75 °C is normal); **-32768 on the TSD20** |
| 34 | 2 | vbat_start_mv | battery right after the sensor rail settled |
| 36 | 2 | vbat_end_mv | battery under sensor load, just before the rail is cut |
| 38 | 2 | crc16 | Zephyr `crc16_ccitt()`: reflected CCITT (poly 0x8408, i.e. 0x1021 bit-reversed), init 0xFFFF, no final XOR, over bytes 0–37 |

Flags (bit set = true):

| bit | name | meaning |
|---:|---|---|
| 0 | TIME_SYNCED | clock had been set from outside (shell / BLE) since boot |
| 1 | TIME_ESTIMATED | clock was restored from the newest record at boot; timestamps are *monotonic but offset* until the next sync |
| 2 | LIDAR_OK | at least one valid distance sample |
| 3 | TILT_OK | IMU read succeeded |
| 4 | MANUAL | triggered from the shell / BLE, not the schedule |
| 5 | FIRST_AFTER_BOOT | first record after a reset (a reset marker for the analysis) |
| 6 | SENSOR_TSD20 | written by the TSD20 firmware variant (`overlay-tsd20.conf`); clear = TFmini Plus. `strength` and `lidar_temp` carry no information when set |
| 7 | RETRIED | the sensor gave no frames at all; it was power-cycled once (1 s off, TSD20: explicit stop → start) and the capture repeated. The statistics are from the second attempt |

Neither time flag set and epoch = 0: the clock had never been set and there
was no previous record to restore from.

Snow depth is *not* stored; it is computed offline from the ZERO reference
(spec §4.5): `depth = (d0 - dist_median) * cos(tilt)`.

## Where records live

1. **Primary: LittleFS on the 2 MB QSPI flash**, mounted at `/lfs1` (the path nRF Connect Device Manager hard-codes).
   One file per month, records appended back to back:
   `/lfs1/rec_YYYYMM.bin` (UTC month), or `/lfs1/rec_notime.bin` while the
   clock is unset. These files are what the BLE file download (mcumgr fs,
   step 4c) fetches. 8 records/day = ~10 kB per month.
2. **Mirror: internal flash partition `mirror_partition`** (0x9F000–0xEC000,
   308 kB = 7,884 records ≈ 2.7 years at 8/day). Raw append-only 40-byte
   slots, written right after the LittleFS append. Used to restore the
   clock estimate and the sequence counter after a reset, for the shell
   `rec dump`, and as the fallback if the QSPI file system is unusable.
   When it is full, records keep going to LittleFS only.
3. **Boot log `/lfs1/boot.log`** (text, one line per boot, rotated to
   `boot.log.1` at 8 kB; deleted by ERASE): `[~]<time> boot=<n> cause=<power/brownout|pin|software|watchdog|lockup|fatal> fatal=<none|cpu-exception|stack-overflow|oops|panic|…> hw=<hwinfo flags> fw=<sensor>[ HALTED]`.
   `~` marks an estimated clock, `boot=n` the consecutive-reset count (1 = clean start).
   Download it with the record files when a device has been misbehaving.

Internal flash layout (overrides the board's UF2 default; the bootloader
regions are untouched):

| address | size | use |
|---|---:|---|
| 0x00000 | 156 kB | Adafruit bootloader / SoftDevice area |
| 0x27000 | 480 kB | application |
| 0x9F000 | 308 kB | `mirror_partition` |
| 0xEC000 | 32 kB | `storage_partition` (settings; calibration data later) |
| 0xF4000 | 48 kB | bootloader UF2 area |

## Clock

The nRF52840 has no calendar RTC. Zephyr's emulated RTC (`rtc-emul`,
ticking from the 32.768 kHz crystal) sits behind the `rtc` alias; it is what
the shell `time` command and, later, the mcumgr `datetime` command set.
The clock is lost on reset: at boot the firmware re-seeds it from the newest
record and marks records TIME_ESTIMATED until the next external sync.

## Shell

Bench shell commands (`rec`, `time`, `cfg`, `cal`, …) are listed in [firmware/README.md](../firmware/README.md).

## Offline decoding

```bash
python3 tools/decode_records.py rec_202612.bin rec_202701.bin > records.csv
```

Bad or torn records are skipped with a message on stderr; the decoder
re-synchronises on the next magic word.

## CSV export (Web Bluetooth page, `docs/app/`)

One row per record, one header row, UTF-8, no comment lines (`pandas.read_csv`
ready). Site columns repeat on every row so files from several loggers can be
concatenated. Missing values are empty.

```
device_id, site_name, lat, lon, alt_m, tz_offset_min,
time_utc, time_local, seq, flags,
dist_cm, dist_var_cm2, strength, n_frames, n_valid, n_out_of_range,
tilt_deg, pitch_deg, roll_deg, imu_temp_c, lidar_temp_c,
vbat_start_mv, vbat_end_mv,
d0_cm, theta0_deg, snow_depth_cm
```

- `time_utc` = `YYYY-MM-DDTHH:MM:SSZ`; `time_local` = ISO 8601 with the site
  offset (`+09:00`), offset from the device setting `sg/sched/tz_min`.
- `flags` = `|`-joined names (see the flag table above).
- `d0_cm`, `theta0_deg` = reference stored on the device, taken either on bare ground (ZERO) or from a probed snow depth at installation (`d0 = d + depth / cos(tilt)`);
  `snow_depth_cm = (d0 - dist_cm) * cos(tilt_deg)` (spec §4.5), empty when
  no reference or no valid distance. Raw `dist_cm` stays, so the depth can be
  recomputed with another reference later.
- Site info comes from `/lfs1/site.json` (written by the page: lat, lon,
  alt_m, accuracy_m, source gps/manual, tz_min, tz_name, set_at, name,
  device_id, history[]).

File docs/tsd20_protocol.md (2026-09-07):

# PONO TSD20 — protocol notes for the firmware variant (step 5)

Source: TSD20 user manual (PDF hosted by Akizuki, https://akizukidenshi.com/goodsaffix/TSD20%20user%20manual.pdf), read 2026-09-04. Product page: 秋月 131304.

## Electrical

| Item | Value | SnowGauge note |
|---|---|---|
| Supply | 3.3–3.6 V DC, peak 70 mA, average 40 mA (< 0.2 W) | Board variant U2 = NJU7223F33 (3.3 V switched rail). **No reverse/overvoltage protection on the sensor** |
| Interface | UART (3.3 V logic) or I2C (addr 0x52, 400 kHz) | UART on D6/D7 as with the TFmini; direct connection |
| Connector | 6-pin 0.8 mm terminal, 20 cm tinned stranded wires | Pin 1 NC, **2 = 3.3 V**, **3 = TX (→ XIAO D7 RX)**, **4 = RX (← XIAO D6 TX via R7)**, 5 NC, **6 = GND**. Wire colours are not in the manual; on our unit (2026-09-07) the connector reads left to right **white, red, yellow, green, light blue, black** = pins 1–6, i.e. **red = 3.3 V, yellow = TX, green = RX, black = GND**, white/light blue unused |
| Range / accuracy | 0.05–20 m (90 % refl.), 0.05–10 m (10 % refl.); ±5 cm < 5 m, 1 % ≥ 5 m; repeatability ±10 mm; resolution 1 mm | Snow: expect the 10 % reflectivity figure |
| Rate | 200 Hz default; 100/50/20/10/1 Hz selectable | 100 frames = 0.5 s at 200 Hz |
| Optics | 905 nm, FOV 3°, spot 5 cm @1 m … 100 cm @20 m; ambient light 8 m @ 100 kLux | Class 1 |
| Temperature | −20…+60 °C | |

## UART

- **460800 8N1 default**. Baud command `5A 06 02 <baud/100 LE16> CK` (115200 = `80 04`, 460800 = `00 12`). Any other rate is rejected. nRF52840 UARTE supports 460800; keep the default unless the breadboard proves noisy.
- **Output frame, 4 bytes, little-endian:** `5C` `distL` `distH` `CK` — distance in **mm** (0–65535), **50000 = out of range / no target**.
- **Checksum:** `CK = ~(sum of bytes from the 2nd to the second-last)` → for the data frame `CK = (uint8_t)~(distL + distH)`.
- **No signal-strength or temperature field** (unlike the TFmini). Quality must come from variance, out-of-range count and frame count only.
- Commands (same checksum rule over bytes 2..n-1):
  - start ranging `5A 0A 02 02 00 F1` (reply `5A 8A 02 02 00 71`), stop `5A 0A 02 00 00 F3`
  - frequency `5A 0B 02 <div LE16> CK`, f = 10000/(div+1): 200 Hz → div 49 (`31 00`), 100 Hz → 99 (`63 00`), 10 Hz → 999 (`E7 03`)
  - serial number `5A 0D 04 0D 0D 0D BA`, software version `5A 16 02 16 16 BB`
  - The sensor streams frames as soon as it is powered (the quick-test section connects and reads immediately); whether the stop/start state is persistent across power cycles is not stated — the driver must not rely on it and should send "start ranging" after the rail settles.

## Bench result (2026-09-07, breadboard, U2 = NJU7223F33, 6.0 V bench supply)

Works with the default sensor settings (460800 baud, 200 Hz): `lidar raw` → `dist=1947 mm`, `lidar read 100` → **100 frames in 499 ms, cksum_err 0**, var 0.00 cm²; `measure` → 100/100 valid in 620 ms, record flags 0x7e (SENSOR_TSD20 set), vbat 5666/5672 mV. Accuracy check: tape measure to the target 194 cm vs sensor 195 cm (+1 cm, spec ±5 cm). A hand at ~0.5 m tracked at 458–511 mm with 1–3 mm frame-to-frame jitter; 1600 frames in 8 s = exactly 200 Hz; no sentinel frames seen (no out-of-range case yet). The static reading is identical across a 100-frame burst (variance 0.00 cm²), i.e. the sensor filters internally, so `dist_var_cm2` will be much smaller than on the TFmini. Raw stream right after `rail on` is the plain 4-byte frame (`5C 9E 07 5A` = 1950 mm), so the sensor streams as soon as it is powered; the start-ranging command is harmless. Wire colours on our unit: white, red, yellow, green, light blue, black = pins 1–6 (red 3.3 V, yellow TX, green RX, black GND). UART logic level is 3.3 V, direct connection (U12 closed).

Gotcha found on the way: `uart_configure()` needs `CONFIG_UART_USE_RUNTIME_CONFIGURE=y` (off by default in NCS 3.4) — without it the call returns -ENOTSUP, the UART stays at the DT 115200 and *zero* bytes arrive (framing errors are dropped silently). Now set in `prj.conf`. Debug shell commands added: `lidar bytes [ms]` (raw hex), `lidar baud <rate>`, `lidar start`, `lidar tx <hex...>`.

Current profile (picowatt, same day): one scheduled cycle 0.95 s, 42 mA while streaming, 650 mA / 2 ms inrush into C4, **35 mA·s = 0.0098 mAh**; sleep + advertising 36 µA ±10 → `docs/measurements/2026-09-07_tsd20_breadboard_current.md`. The sensor starts streaming ~150 ms after the rail comes up, so `CONFIG_SNOWGAUGE_RAIL_SETTLE_MS` could drop to ~200 ms (not changed). Still open: behaviour on a no-target / out-of-range surface (sentinel 50000 not yet seen), second release asset.

## Implementation status (2026-09-04)

Implemented and built (both variants):

- `firmware/src/lidar.h` / `lidar.c`: common UART receiver + burst statistics; backends `tfmini.c` (default) and `tsd20.c`, selected by the Kconfig choice `SNOWGAUGE_SENSOR` (`overlay-tsd20.conf`). The baud rate is set at run time by `lidar_init()` (`uart_configure`, 460800; requires `CONFIG_UART_USE_RUNTIME_CONFIGURE=y`), so no DT overlay is needed.
- `tsd20.c`: 4-byte parser with resync on a false 0x5C header, mm → cm rounding, sentinel 50000 (and 0) → `n_invalid`, `strength = 0`, `temp_c_x10 = INT16_MIN`; "start ranging" sent by `sensor_rail_on()` after the settle time; `lidar rate <hz>` → frequency command (div = 10000/hz − 1). Host unit test of the parser and command checksums passed (start = `5A 0A 02 02 00 F1`, 100 Hz = `5A 0B 02 63 00 8F`).
- Record flag bit 6 `SENSOR_TSD20`; BLE name `SG-TSD-XXXX` (TFmini build: `SG-TFM-XXXX`; the page filters on `SG-`); `tools/decode_records.py` and the CSV flag names updated; `CONFIG_SNOWGAUGE_VBAT_MIN_MV` defaults to 3800 for the TSD20.
- Shell: `lidar read|raw|rate|save|info` (`tsd20` / `tfmini` as aliases). `lidar raw` prints `dist=xxxx mm`.
- Breadboard: `docs/breadboard_guide_tsd20.html` (generated with `gen_breadboard.py --tsd20`), §5 = conversion steps from the TFmini build.

Open until the bench run: settle time (`CONFIG_SNOWGAUGE_RAIL_SETTLE_MS` 300 ms may be shortened), whether 460800 is clean on the breadboard wires, current profile (expect ≈40 mA × 0.5 s), whether the stop/start state persists across power cycles, and whether the sensor ever emits 0 mm.

## Firmware plan (step 5, written before the implementation)

1. `Kconfig` choice `SNOWGAUGE_SENSOR` = `TFMINI` (default) | `TSD20`; `overlay-tsd20.conf` selects it and sets `uart0` `current-speed = <460800>` via a DT overlay fragment.
2. Put the sensor behind `lidar.h` (`lidar_init/flush/capture/read_frame/set_frame_rate`, `struct lidar_stats` = today's `tfmini_stats`); `tfmini.c` and new `tsd20.c` implement it. TSD20: 4-byte parser, mm → cm (round) for the v1 record, sentinel 50000 → `n_invalid`, `strength_median` = 0 and `n_weak` = 0 (no strength), `temp_c_x10` = INT16_MIN.
3. Rail: unchanged (`SENSOR_EN`); settle time may be shorter; measure boot-to-first-frame with the shell `tfmini raw` equivalent (`lidar raw`).
4. Record: set new flag bit 6 `RECORD_FLAG_SENSOR_TSD20` so CSV/analysis can tell the variants apart (update `record.h`, `docs/record_format.md`, `app.js` `RECORD_SCHEMA.flags`, `tools/decode_records.py`). BLE name `SG-TSD-XXXX` for the TSD20 build (`SG-TFM-XXXX` for the TFmini; app filter `SG-` matches both).
5. Release as a second asset in the same tag: `snowgauge_fw_<date>_tsd20.uf2` / `_tsd20_dfu.zip`.
6. Bench: same STEP 5 check with the TSD20 on the 3.3 V rail (U2 = F33), current profile with picowatt (expect ≈ 40 mA × 0.5 s per measurement).

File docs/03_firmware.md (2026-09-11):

# 03. ファームウェアの書き込み

SnowGauge 本体（XIAO nRF52840 Sense）に、公開済みのファームウェア（本体のプログラム）を書き込む手順です。
工学の知識は不要です。書いてあるとおりに進めてください。

- 本体を自分で組み立てた直後（初回の書き込み）
- 新しい版のファームウェアが出たとき（更新）

のどちらも、この手順で行います。書き込みは USB 経由で行い、**設定・記録データは消えません**（記録は QSPI フラッシュに、設定は別領域に入っています）。

---

## 1. 用意するもの

| もの | 備考 |
|---|---|
| USB-C ケーブル | **データ通信対応**のもの。充電専用ケーブルでは PC に認識されません |
| PC | Windows / macOS / Linux のいずれか。Chrome が入っていると後の確認（04 章）にも使えます |
| SnowGauge 本体 | XIAO が載った基板（または開発用ブレッドボード） |

### 安全上のきまり（必ず守る）

> **USB と電池（または安定化電源）を同時につながない。**
> - **基板（PCB）**: USB をつなぐ前に**電池を外す**。書き込みが終わって USB を抜いてから電池をつなぐ。
> - **ブレッドボード**: ジャンパ ⑩ を抜いてあるときだけ同時接続可（`docs/breadboard_guide.html` 参照）。抜いていなければ USB をつなぐ前に電源を外す。

---

## 2. ファームウェアをダウンロードする

公開場所（GitHub Release）:

**https://github.com/0kam/SnowGauge/releases/tag/fw-2026-09-11**

ページ下部の "Assets" に 3 つのファイルがあります。用途に合わせて 1 つだけ落とせば十分です。

| ファイル | 使い方 |
|---|---|
| `snowgauge_fw_2026-09-11.uf2` | **方法 A**（ドラッグ＆ドロップ）。Windows / Linux / 古めの macOS |
| `snowgauge_fw_2026-09-11_dfu.zip` | **方法 B**（シリアル DFU）。**macOS 26** ではこちらが必須 |
| `snowgauge_fw_2026-09-11.hex` | 開発者向け（自分でパッケージを作る場合）。通常は不要 |
| `snowgauge_fw_2026-09-11_tsd20.uf2` / `_tsd20_dfu.zip` / `_tsd20.hex` | 上の 3 つの **TSD20 版**（下記参照） |

**TSD20 版の本体**（U2 = NJU7223F33、センサが TSD20）には、ファイル名に `_tsd20` が付いた方（`snowgauge_fw_<日付>_tsd20.uf2` / `_tsd20_dfu.zip`）を書き込みます。TFmini 版のファームウェアを TSD20 本体に入れても（またはその逆でも）壊れはしませんが、距離が読めません。見分け方: 本体の名前で分かります。TFmini 版は `SG-TFM-XXXX`、TSD20 版は `SG-TSD-XXXX`（`fw-2026-09-07` 以前のファームウェアは `SG-XXXX`）。

新しい版が出ると Release のタグ名（`fw-YYYY-MM-DD`）が変わります。ファイル名の日付も同じです。

---

## 3. 方法 A: UF2 ファイルをドラッグ＆ドロップ（Windows / Linux / 古い macOS）

XIAO には「ブートローダ」という小さな書き込みプログラムが最初から入っていて、USB メモリのふりをしてくれます。そこにファイルをコピーするだけで書き込みが終わります。

1. 電池を外す（上の安全上のきまり）。
2. USB-C ケーブルで本体と PC をつなぐ。
3. XIAO の **RESET ボタン**（USB-C コネクタのすぐ横にある小さなボタン）を**すばやく 2 回**押す（ダブルクリックの要領、0.5 秒以内に 2 回）。
   - 成功すると、PC に **`XIAO-SENSE`** という名前のドライブ（USB メモリのようなもの）が現れます。
   - 現れないときは、間隔を変えてもう一度ダブルタップしてみてください。
4. ダウンロードした `snowgauge_fw_2026-09-11.uf2` を **`XIAO-SENSE` ドライブにコピー**（ドラッグ＆ドロップ）する。
5. 数秒でドライブが自動的に消え、本体が再起動します。これで書き込み完了です。
   - Windows で「ドライブが正しく取り外されませんでした」のような警告が出ても問題ありません。
6. USB を抜いてから電池をつなぐ（現地に持っていく場合）。

### うまくいったかの確認（3 つのうちどれかで OK）

| 確認方法 | 見え方 |
|---|---|
| USB シリアル（第 5 節） | `sg:~$` という入力待ち（プロンプト）が出て、`help` と打つと `cal` `cfg` `rec` などのコマンドが並ぶ |
| アプリ（04 章） | 「接続」を押すと **`SG-TFM-XXXX`** または **`SG-TSD-XXXX`**（XXXX は本体ごとの英数字 4 桁）が候補に出る |
| ドライブ | `XIAO-SENSE` ドライブが**消えたまま**で、再び出てこない |

> **緑 LED について**: この本体の緑 LED は「観測を 1 回行うたびに 50 ms 光る」だけで、起動時には光りません。書き込み直後は自動観測が約 10 分間止まる（再起動直後の保留時間）ため、**LED が光らなくても失敗ではありません**。確認には上の 3 つを使ってください。

---

## 4. 方法 B: シリアル DFU（macOS 26 など、ドライブが出てこない PC）

macOS 26 は XIAO の `XIAO-SENSE` ドライブをマウントできません（Finder に出てこない）。この場合は、`adafruit-nrfutil` というコマンドラインツールで書き込みます。Windows / Linux でも同じ手順が使えます。

### 4.1 一度だけ: ツールを入れる

「ターミナル」（macOS: アプリケーション → ユーティリティ → ターミナル）を開き、次を実行します（Python 3 が必要です）。

```bash
pip install adafruit-nrfutil
```

`pip` が見つからないと言われたら `pip3 install adafruit-nrfutil` を試してください。

### 4.2 本体をブートローダにする

電池を外し、USB をつないでから、どちらかの方法で本体を「書き込み待ち」状態にします。

- RESET ボタンを**すばやく 2 回**押す（方法 A と同じ）、または
- すでに SnowGauge ファームウェアが入っている本体なら、USB シリアル（第 5 節）で `dfu` と打つ。

### 4.3 ポート名を調べる

ターミナルで

```bash
ls /dev/cu.usbmodem*
```

と打つと、`/dev/cu.usbmodem21101` のような名前が出ます（数字は USB ポートによって変わります）。これが `<port>` です。
Windows では「デバイス マネージャー」→「ポート (COM と LPT)」に `COM5` のように出ます。Linux では `/dev/ttyACM0` です。

### 4.4 書き込む

ダウンロードした zip のあるフォルダで（`cd ~/Downloads` など）:

```bash
adafruit-nrfutil dfu serial --package snowgauge_fw_2026-09-11_dfu.zip -p /dev/cu.usbmodem21101 -b 115200 --singlebank
```

`-p` のあとは 4.3 で調べたポート名に置き換えます。進捗バーが 100% まで進み、`Device programmed.` と出れば完了です。本体は自動的に再起動します。確認方法は方法 A と同じです。

---

## 5. USB シリアルで本体と会話する（動作確認）

ファームウェアには「シェル」という文字で会話する機能があり、USB でつないだ PC から本体の状態を見たり、試しに観測させたりできます（現地では使いません。机の上での確認用です）。

### 5.1 シリアルターミナルを開く（通信速度 115200）

**macOS**（ターミナル）:

```bash
ls /dev/cu.usbmodem*                 # ポート名を調べる
screen /dev/cu.usbmodem21101 115200  # 名前は自分のものに
```

終了は `Ctrl+A` を押してから `K`、`y`。

**Windows**: Tera Term または PuTTY を使います。
- Tera Term: 起動 → 「シリアル」を選び、ポートに `COM5` など（USB シリアル デバイス）を選ぶ → 「設定」→「シリアルポート」でスピードを **115200** に。
- PuTTY: Connection type = Serial、Serial line = `COM5`、Speed = `115200` → Open。

**Linux**: `screen /dev/ttyACM0 115200`（権限エラーなら `sudo usermod -aG dialout $USER` して再ログイン）。

画面が空のままなら **Enter を 1 回**押してください。`sg:~$ ` と出れば会話できています。

### 5.2 まず打ってみるコマンド

| コマンド | 何が分かるか |
|---|---|
| `help` | コマンド一覧。`cal` と `cfg` があれば今回の版（2026-09-04 以降）です |
| `rec count` | 記録の件数、記録用ファイルシステムの状態（`fs=mounted` が正常）、最新の記録 |
| `time` | 本体の時計（UTC）と状態: `synced`（同期済み）/ `estimated`（前回記録から推定）/ `unset`（未設定） |
| `cfg show` | 観測スケジュール（開始・終了・間隔・タイムゾーン）、基準値 d0/θ0、次回の自動観測時刻 |
| `ble` | Bluetooth の広告（アプリから見えるための信号）が出ているか。`SG-TFM-XXXX` / `SG-TSD-XXXX` の名前もここで分かる |
| `measure` | **その場で 1 回観測**して記録に保存する。傾斜 → センサ通電 → 電池 → 距離 100 回 → 電池 → 遮断、を約 1.6 秒で行い、結果を CSV 1 行で表示 |

`measure` の結果の見方: `median`（距離の中央値 cm）、`var`（ばらつき cm²）、`strength`（信号強度）、`vbat`（電池 mV）。詳しくは `firmware/README.md` の "Shell output fields"。

### 5.3 その他の便利なコマンド

| コマンド | 説明 |
|---|---|
| `rec ls` | 記録ファイルの一覧（`rec_YYYYMM.bin`、月ごと） |
| `rec dump [n]` | 新しい方から n 件の記録を CSV で表示（省略時 10 件、`rec dump 0` で全部） |
| `rec erase ERASE` | **全記録を消す**（`ERASE` を大文字で付けないと拒否されます） |
| `time set <epoch>` | 時計を合わせる。`<epoch>` は UTC の秒数。macOS/Linux のターミナルで `date +%s` と打つと今の値が出ます。通常はアプリの「同期」で合わせるので不要 |
| `cfg sched <開始 HH:MM> <終了 HH:MM> <間隔 分> [tz 分]` | スケジュール設定（例 `cfg sched 00:00 00:00 180 540` = 終日 3 時間ごと、日本時間） |
| `cal zero [積雪深 cm]` | 基準値を取る（アプリの「ZERO」「積雪深で基準設定」と同じ） |
| `cal clear` | 基準値を消す |
| `batt` | 電池電圧 |
| `tilt` | 傾斜角（光軸の真下からのずれ。基板を鉛直・USB 左・センサ端子 J2 上に立てたとき 0° 付近） |
| `rail on` / `rail off` / `rail status` | センサ電源の入・切・状態（`lidar read` の前に `rail on` が必要） |
| `lidar read [n]` | 距離センサから n 回読んで統計を表示（`tfmini read` / `tsd20 read` も同じ） |
| `lidar raw [ms]` | 生の距離フレームを流す（TSD20 版は mm 表示） |
| `lidar info` | どちらのセンサ版のファームウェアか（`sensor=TFmini Plus` / `TSD20`）を表示 |
| `auto <秒>` | 机上テスト用: 指定秒ごとに自動観測（`auto 0` で止める）。スケジュールより優先されます |
| `reboot` | 再起動 |
| `dfu` | ブートローダに入る（方法 B の書き込み待ち状態） |

> 開発用の新品ボードには、動作テスト用の基準値 d0 が入っていることがあります。**現地に設置するときは必ずアプリで ZERO か「積雪深で基準設定」をやり直してください**（04 章）。

---

## 6. 困ったとき

| 症状 | 対処 |
|---|---|
| `XIAO-SENSE` ドライブが出てこない | (1) macOS 26 → 方法 B。(2) ケーブルが充電専用でないか確認（別のケーブルを試す）。(3) ダブルタップの速さを変えて再挑戦。(4) PC の別の USB ポートに挿す。(5) USB ハブ経由をやめて直挿し |
| 方法 B で転送が途中で止まり、本体が再起動してしまう | 自分で `adafruit-nrfutil dfu genpkg` した zip の場合、`--sd-req 0xFFFE` を付けていないと（`0x00` だと）ブートローダが拒否します。Release の zip は正しく作ってあるので、まず Release の zip を使ってください |
| 方法 B で `No such file or directory: '/dev/cu.usbmodem…'` | ポート名が違います。4.3 をやり直す。ブートローダに入る前後で番号が変わることがあります。Windows は `COM5` のような名前 |
| 方法 B で `Timeout` | 本体がブートローダになっていません。RESET をダブルタップしてから 10 秒以内にコマンドを実行 |
| ドライブが何度も出てくる / アプリに `SG-…` が出ない | アプリのプログラムが起動していません（ブートローダのまま）。RESET を **1 回**押してみる。直らなければもう一度書き込む |
| シリアルで何も出ない | Enter を押す。別のプログラム（Arduino IDE のシリアルモニタ、もう 1 つの `screen`）がポートを使っていないか確認。ケーブルを挿し直す |
| シリアルに文字化け | 速度が 115200 になっているか確認 |
| `time` が `unset` のまま | 正常です（電源を入れ直すと時計はリセットされます）。現地でアプリの「同期」を押せば合います |

---

## 7. ソースから自分でビルドしたい人へ

開発者向けの手順（nRF Connect SDK v3.4.0、`west build`、パッケージの作り方）は英語で
[`firmware/README.md`](../firmware/README.md) にまとめてあります。

## 補足

- 書き込みが終わったら **USB を抜いてから電池（または電源）をつなぎ直して**ください。基板は電源が入ると数秒で `SG-TFM-XXXX`（TSD20 版は `SG-TSD-XXXX`）として BLE に現れ、アプリから見えるようになります。
- 書き込み直後の本体には、開発時に試験用の基準値（d0）や観測スケジュールが残っていることがあります。設置時にアプリで基準を取り直し、スケジュールを確認してください（[04_app.md](04_app.md)）。

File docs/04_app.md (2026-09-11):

# 04. アプリの使い方（現地作業）

SnowGauge の現地作業は、スマホ（または PC）のブラウザで動く 1 ページのアプリで行います。
本体と Bluetooth でつながり、**時刻合わせ・データ回収・観測スケジュール変更・設置時の照準と基準設定**ができます。
ケーブルは要りません。ボタンは手袋でも押せるように大きくしてあります。

アプリの URL: **https://0kam.github.io/SnowGauge/app/**

---

## 1. 準備（出発前に、電波のあるところで）

### 1.1 使える端末

| 端末 | 使い方 |
|---|---|
| **Android スマホ + Chrome** | 推奨。URL を開くだけで動きます |
| **PC（Windows / macOS / Linux）+ Chrome** | Bluetooth 内蔵か USB Bluetooth アダプタが必要 |
| iPhone / iPad | Safari では動きません。App Store の **Bluefy** というブラウザを入れて、その中で URL を開きます |

### 1.2 ホーム画面に追加する（Android）

1. Chrome で上の URL を開く。
2. 右上の「⋮」メニュー → **「ホーム画面に追加」**（機種によっては「アプリをインストール」）。
3. ホーム画面の SnowGauge アイコンから起動できるようになります。

### 1.3 出発前に一度オンラインで開く

アプリは一度開くとスマホに保存され、**山の中（圏外）でもそのまま動きます**（オフライン優先）。
ただし更新は開いたときにしか取り込まれないので、**現地に行く前に電波のあるところで一度開いてください**。
新しい版が来ると下の方に「新しい版を取得しました。次回起動時に切り替わります」と出ます。その場合はタブを閉じてもう一度開きます。

いま使っている版は、ページ一番下の「ログ」欄の下に **「アプリ版 2026-09-05a」** のように表示されます（この文書はこの版に対応）。

### 1.4 スマホ側の許可

- **Bluetooth** をオンにする。
- Chrome に**位置情報の許可**を与える（「同期」で GPS を使います。Android では Bluetooth 機器を探すのにも位置情報の許可が要ることがあります）。

---

## 2. 本体につなぐ・切る

画面一番上の帯（ヘッダー）に、接続状態と **「接続」** ボタンがあります。

1. 本体のそばで **「接続」** を押す。
2. Chrome の小さな窓に近くの機器が並びます。**`SG-TFM-XXXX`**（TFmini 版）または **`SG-TSD-XXXX`**（TSD20 版）（XXXX は本体ごとに違う英数字 4 桁。これが本体の名前です。古いファームウェアでは `SG-XXXX`）を選び、「ペア設定」を押す。
3. ヘッダーが **「接続中: SG-TFM-XXXX」** に変わり、灰色だったボタンが押せるようになります。同時にアプリが本体の時刻・設定・サイト情報を自動で読み込みます。

作業が終わったら **「切断」** を押します。
時刻を合わせていない（本体とスマホの時刻差が 60 秒より大きい）状態で「切断」を押すと、赤い注意
「時刻が未同期です。同期せずに切断するならもう一度押してください」が出て、すぐには切れません。ふつうは先に「同期」を押してください。

> 本体には一度に 1 台しかつながれません。また、つないでいる間は本体の自動観測が続きますが、ライブ表示中の分は飛びます（第 4 節）。

---

## 3. 画面の 4 つのパネル

### パネル 1「同期」

| 表示・ボタン | 意味 |
|---|---|
| 本体時刻: | 本体の時計（UTC）と、スマホとの差（秒）。差が 60 秒以内なら緑、それ以上なら橙 |
| サイト: | 本体に保存されているサイト名・緯度経度・標高・精度・設定日時。未設定なら「サイト情報なし」 |
| UTC+09:00（同期時にスマホから自動設定） | タイムゾーン。スマホの設定から自動で入るので、操作は不要 |
| 入力欄「サイト名（例: 苗場A）」 | 設置場所の名前。**「同期」を押す前に入力**します。空欄なら前回の名前が残ります |
| **「スマホの時刻・位置で同期」** | メインのボタン。**時刻・タイムゾーン・GPS 位置** を一度に本体へ書き込みます。GPS 取得に最大 20 秒かかります |
| ▸「時刻のみ / 位置を手動入力」 | 開くと補助ボタンが出ます: **「時刻のみ同期」**（GPS を使わない）、緯度・経度・標高 m の入力欄と **「位置を手動で保存」** |

GPS が取れなかったときは、時刻とタイムゾーンだけ書き込まれ、「失敗: 1 件の問題（ログ参照）」と出ます。屋外で空が開けた場所ならもう一度押すか、緯度経度を手動で入れてください。

### パネル 2「観測データ」

| 表示・ボタン | 意味 |
|---|---|
| **「ダウンロードして CSV 保存」** | 本体の記録を全部読み出し、**そのまま CSV ファイルを保存**します。進み具合が下に出ます（`rec_202612.bin: 1200/4000 B` など）。件数が多いと数十秒〜数分 |
| グラフ | 基準値が設定されていれば**積雪深**、なければ**斜距離**の時系列。上端の赤い帯は欠測区間 |
| 「N 件、要確認 n 件（一覧は新しい 30 件…）」 | 読み出した件数のまとめ。**「すべて表示」**で全件に切り替え |
| 表 | 現地時刻（月-日 時:分）/ 距離 / 積雪 / 傾斜 / 電池 / 有効。気になる点がある行は橙色になり、その下に「要確認: 理由」の行が出ます（第 6 節） |
| **「共有して保存」**（iPhone のみ表示） | iPhone（Bluefy）は普通のダウンロードができないため、**共有シート →「ファイルに保存」**で保存します。共有シートが出ないときは ▸「共有できないとき」から**コピー**または**別タブで開く** |
| ▸「もう一度保存 / 生データ / 文字コード」 | **「CSV をもう一度保存」**（同じ内容を再保存）、**「生データ保存」**（本体のファイルそのもの `rec_YYYYMM.bin` と `site.json`。解析で困ったときの保険）、**CSV の文字コード**（既定 UTF-8。Mac の Excel で開くときだけ Shift_JIS にして保存し直す。選択は端末に記憶されます） |

CSV の中身は [05_data.md](05_data.md) を見てください。

### パネル 3「観測スケジュール」

| 項目 | 意味 |
|---|---|
| 観測開始 / 観測終了 | 自動観測する時間帯（現地時刻、30 分刻み）。**開始と終了を同じにすると終日**。開始が終了より後なら夜をまたぎます（例 17:00 → 05:00） |
| 観測間隔 | 5 分〜24 時間から選ぶ（5・10 分は試験用。運用では 30 分以上）。「自動観測しない」にすると止まります |
| 基準斜距離 d0 / 基準傾斜 θ0 / 基準設定日時 | パネル 4 で設定した基準値の表示（ここでは変えられません） |
| **「保存」** | 変更を本体に書き込む。押すまで本体は変わりません |
| **「再読込」** | 本体の値を読み直す（変更をやめたいとき） |

> 標準的な設定は「終日・3 時間ごと」（8 回/日）です。間隔を短くすると電池が早く減ります。
> 本体は再起動（電池交換など）のあと約 10 分は自動観測を待ちます。すぐ 1 回測らせたいときは、パネル 4 のライブ表示で確認してください。

### パネル 4「設置・基準設定」

| 表示・ボタン | 意味 |
|---|---|
| 基準: | 今の基準値 `d0 = 245 cm, θ0 = 12.30°`、または「未設定（無雪 ZERO か積雪深入力で設定）」 |
| ライブ: | 「停止」か「動作中（センサ通電中、5 分で自動停止）」 |
| 数字のタイル | **斜距離 cm**（センサが測った生の距離）、**鉛直距離 cm**（傾き（レーザーの真下からのずれ、[coordinate_system.md](coordinate_system.md)）を補正した真下方向の距離 = 斜距離 × cos 傾斜）、**積雪 cm**（基準値があるときだけ）、**傾斜 °**、**信号強度**、**電池 mV**、**有効/総**（10 回中いくつ有効だったか。`10/10, var 1` のように、ばらつきも出ます） |
| **「ライブ開始」** / **「ライブ停止」** | センサに通電して約 0.25 秒ごとに数字を更新。**照準合わせ用** |
| **「ZERO（無雪の地面）」** | 雪のない地面を測って、それを積雪 0 の基準にする。**2 回押し**（下記）。約 3 秒 |
| 積雪深の選択（0〜400 cm）+ **「積雪深で基準設定」** | すでに雪がある状態で設置したとき。スノープローブ等で測った**今の積雪深**を選んでから押す。**2 回押し**。本体が「今の距離 + 積雪深 ÷ cos 傾斜」を基準 d0 として保存します |
| **「状態更新」** | 基準値とライブの状態を本体から読み直す |
| **「全レコード消去」**（赤） | 本体の記録を全部消す。**2 回押し**。このセッションで「ダウンロードして CSV 保存」を済ませるまで押せません（灰色のまま、下に理由が出ます） |

### 「ログ」欄

一番下。アプリが何をしたか（接続、時刻設定、ファイル名と件数、エラー）が時刻付きで残ります。うまくいかないときはここを見て、必要なら写真に撮って報告してください。その下に「アプリ版 …」があります。

### ボタン操作の共通ルール

- 押すとボタンが「処理中…」になり、終わると画面下に「完了」または「失敗: 理由」が短く出ます。処理中は他のボタンが押せません。
- **2 回押し**が必要なボタン（ZERO・積雪深で基準設定・全レコード消去・未同期での切断）は、1 回目でボタンが
  「確認: 1.5 秒後にもう一度押すと実行」に変わります。**1.5 秒以上あけて、6 秒以内**にもう一度押すと実行されます。1.5 秒以内の連打は無視され、6 秒たつと元に戻ります（手袋での誤操作を防ぐためです）。

---

## 4. 現地の手順（チェックリスト）

### 設置時

1. 本体を取り付け、電池をつなぐ（**入切を繰り返さず一度でしっかり**。理由は下の注）。アプリで **「接続」** → `SG-…` の本体名を選ぶ。
2. 「サイト名」を入力し、**「スマホの時刻・位置で同期」**。「本体時刻」が緑になり、「サイト:」に名前と緯度経度が出ることを確認。
3. **「ライブ開始」**。**斜距離**の数字が出て、**有効/総**が 9/10 以上、**信号強度**が数百以上あるように向きを調整する（雪面・地面に対して、たとえば 20〜30° 斜め下）。数字が `---` のままなら、対象が近すぎる／遠すぎる／向きが外れています。
4. 向きが決まったら **「ライブ停止」**。
5. 基準を作る（どちらか）:
   - 雪がない → **「ZERO（無雪の地面）」** を 2 回押し。
   - 雪がある → プローブで積雪深を測り、選択欄で選んで **「積雪深で基準設定」** を 2 回押し。
   「基準:」に `d0 = … cm, θ0 = …°` が出れば成功。
6. パネル 3 の **観測開始・終了・間隔** を確認し、変えたら **「保存」**。
7. **「切断」**。しばらくして本体の緑 LED が観測のたびに短く光ります（最初の自動観測は約 10 分後以降）。

> **注: 電池の入れ直しと「10 分」について**
> 本体は電源が入り直すたびに「ブラウンアウト（電池切れかけで測定中に落ちる）のループかもしれない」と考え、電池を守るために最初の自動観測を **10 分 × 入り直した回数**だけ遅らせます。12 回に達すると、その場では自動観測を止めます（BLE は生きているので接続はできます）。
> **設置作業で一度アプリを接続すれば、この遅延と停止は解除されます**（人が現地にいるのでループではない、と本体が判断する。`fw-2026-09-11` 以降）。手順 1 で接続しているので、通常は意識する必要はありません。接触が悪くて電池を何度も入れ直したときは、**最後にもう一度接続してから帰ってください**。

### 巡回時（データ回収）

1. **「接続」** → `SG-…` の本体名。
2. **「スマホの時刻・位置で同期」**（時計のずれを直します。位置は前回と同じでも構いません）。
3. **「ダウンロードして CSV 保存」**。「合計 N 件」と出て、CSV がスマホに保存されます。表とグラフをざっと見て、**電池 mV** と「要確認」の数を控える。
4. （任意）本体の記録を空にしたいときだけ **「全レコード消去」** を 2 回押し。消去しなくても新しい記録は追記されます（2 MB で数年分入ります）。
5. **「切断」**。

---

## 5. きまりと注意

- **帰る前に必ず「同期」**。本体の時計は電池を抜くとリセットされ、次に電源が入ると「前回の記録の時刻」から動き出します（実際より遅れた時刻）。同期するまでの記録には「時刻推定」が付きます。
- **ライブ表示はセンサに約 120 mA 流れます**（通常の待機は約 0.03 mA = 26 µA）。確認が終わったらすぐ「ライブ停止」。切断すると自動で止まり、5 分たっても自動で止まります。ライブ中に予定時刻が来た自動観測は 1 回飛びます。
- **消去は CSV を保存した後だけ**。アプリ側でもボタンが押せないようにしてあり、本体側でも「このセッションで読み出し済み」でないと拒否します（「ダウンロード前の消去は拒否されました」）。
- 「ZERO」「積雪深で基準設定」は、ライブ表示で距離と傾斜がちゃんと出ている状態で行ってください。出ていないと「測距か傾斜が取れていません」で失敗します。
- 基準値は本体に 1 組だけ保存されます。設定し直すと前の値は上書きされます（CSV には生の距離も入っているので、あとから計算し直せます。05 章）。
- タイムゾーンはスマホの設定が自動で入ります。海外設定のスマホを使わないこと。
- **CSV の保存先（Android）**: Chrome の「ダウンロード」フォルダ（内部ストレージ/Download）。ファイル名は `SG-TSD-6E63_2026-12-31-03-15-20.csv` のように本体名 + 保存時刻。
- **iPhone（Bluefy）**: ダウンロードは保存されません。「ダウンロードして CSV 保存」のあとに出る**「共有して保存」→「ファイルに保存」**を使ってください。
- **CSV の文字コード**: 既定は UTF-8。**化けるかどうかは開くアプリで決まります**（2026-09-11 に実測。サイト名「テスト」で確認）。

| 開き方 | 結果 | 対処 |
|---|---|---|
| PC の Google スプレッドシート | ○ 正常 | そのまま |
| PC の R / Python / テキストエディタ | ○ 正常 | そのまま |
| **Mac の Excel** | × `繝せ繝`（Shift_JIS として読むため） | ▸「もう一度保存 / 生データ / 文字コード」で **Shift_JIS** を選んで保存し直す |
| **Android のスプレッドシートアプリ** | × `ãƒ†ã‚¹ãƒˆ`（何を渡しても Latin-1 として読む） | 文字コードでは直りません。**PC に送ってから開いてください**（数値データは壊れていないので、現場での確認はアプリの表とグラフで足ります） |
- 「本体時刻」の差が数秒あるのは正常です。

---

## 6. 「要確認」に出る言葉の意味

| 表示 | 意味 | どう考えるか |
|---|---|---|
| 測距なし | 100 回のうち有効な距離が 1 回もない | 雪面が遠すぎる／近すぎる、レンズの雪や結露、向きのずれ。次の巡回で目視確認 |
| 有効率低 | 有効な回数が半分未満 | 降雪中・霧・レンズ汚れの可能性。距離は残るが信頼度は低め |
| ばらつき大 | 100 回の距離のばらつき（分散）が 4 cm² 超 | 降雪中、風で揺れる、対象が斜めすぎる |
| レンジ外多 | センサが「測れない」と返した回数が半分超 | 測距なしに近い状態 |
| 時刻推定 | 再起動後、同期前の記録 | 時刻が遅れている可能性。05 章の説明を参照 |
| 時刻なし | 時計が一度も合っていない状態の記録 | 設置時に同期を忘れた。順番だけは正しい |
| 欠測あり | 前の記録から観測間隔の 1.5 倍以上あいている | 電池切れ・再起動・ライブ中のスキップなど |
| 電池低 | 電池電圧が 4400 mV 未満 | 次の巡回で電池交換。通電直後の電圧が 4600 mV を切ると本体は距離測定をやめます |

---

## 7. オフラインでの使い方

- アプリ本体はスマホに保存されているので、圏外でも「ホーム画面に追加」したアイコンから起動できます。
- 「同期」の位置情報は GPS なので圏外でも取れます（空が見える場所で 20 秒ほど）。
- 更新は電波のあるところで開いたときにだけ取り込まれます（1.3 節）。

---

## 8. 困ったとき

| 症状 | 対処 |
|---|---|
| 「接続」を押しても `SG-…` が出てこない | 本体は 1〜2 秒に 1 回しか信号を出しません。窓を閉じてもう一度「接続」を押す（数回）。本体に近づく（数 m 以内）。**別のスマホがつながったままになっていないか**確認（つながっている間は見えません）。電池が入っているか確認。それでもだめならスマホの Bluetooth を一度オフ→オン |
| Chrome の機器一覧に何も出ない（Android） | Chrome の位置情報許可と、端末の位置情報（GPS）がオンか確認 |
| 赤い帯「このブラウザは Web Bluetooth に対応していません」 | iPhone の Safari、または Firefox 等。Android/PC の Chrome か、iPhone なら Bluefy を使う |
| ログに「本体 FW が設定グループ未対応: 4d 版が必要」/「キャリブレーション用サービスが本体にありません」 | 本体のファームウェアが古い。[03_firmware.md](03_firmware.md) の手順で Release `fw-2026-09-04` 以降を書き込む |
| 「失敗: 本体の応答がありません（タイムアウト）」 | 電波が弱い。近づいてもう一度。直らなければ「切断」→「接続」 |
| 「本体が前のコマンドを処理中です」 | 数秒待ってからもう一度 |
| ダウンロードの途中で止まる | 「切断」→「接続」→ もう一度「ダウンロードして CSV 保存」（最初からやり直しますが、本体のデータは消えません） |
| 画面が古い／ボタンの表示がこの文書と違う | タブを閉じて（ホーム画面のアイコンからなら一度終了して）開き直す。電波のあるところで開くと最新版になる |
| CSV がどこにあるか分からない | Chrome の「⋮」→「ダウンロード」。「CSV をもう一度保存」で再保存もできます |
| iPhone（Bluefy）で押しても何も保存されない | Bluefy はダウンロードを保存できません。**「共有して保存」→「ファイルに保存」**を使います（ボタンは読み出し後に出ます）。それも出ないときは ▸「共有できないとき」→「クリップボードにコピー」 |
| 開いた CSV の日本語（サイト名）が化ける | ファイルは壊れていません（化けるのはサイト名だけで、**数値データは無事**）。開くアプリの問題です。上の表を参照: Mac の Excel なら **Shift_JIS** で保存し直す、Android のスプレッドシートなら PC に送ってから開く |
| 「切断」が 1 回で切れない | 時刻が未同期です。「同期」を押してから切断するか、承知の上ならもう一度押す |
| 設置したのに記録が増えない（巡回で来たら数件しかない） | 電源の入り直しで自動観測が遅延・停止していた可能性があります（上の「10 分」の注）。**一度「接続」すれば解除**されるので、接続してから 10 分以内に記録が増え始めるか確認してください。次の設置からは電池を入れ直したあと必ずアプリを接続してから帰る |

## 補足

- 記録が 0 件のときは本体側は消去を受け付けますが、アプリの消去ボタンは「ダウンロードして CSV 保存」を一度押した後に有効になります（0 件でも押してください。CSV は作られません）。
- 最初の観測は、本体の再起動から 10 分後以降に始まります（再起動を繰り返した場合はさらに延びます）。設置直後に記録が増えなくても故障ではありません。

## 野外で快適に使うために

### Android（推奨）

1. **アプリ化**: Chrome で https://0kam.github.io/SnowGauge/app/ を開き、メニュー（⋮）→「ホーム画面に追加」（機種により「アプリをインストール」）。ホーム画面のアイコンから全画面で起動し、**圏外でも動きます**。
2. **出発前に一度、電波のある場所で起動**する。これだけで最新版がキャッシュされ、ログ欄の下の「アプリ版」が更新されます（山では更新できません）。
3. **Bluetooth と位置情報を ON** にする。Android では Bluetooth 機器の検索に位置情報の許可が必要な機種があります。最初の接続時に Chrome が「付近のデバイス」「位置情報」の許可を求めたら許可してください。位置情報は「同期」で観測点の座標を記録するためにも使います。
4. **省電力設定に注意**: 画面が消えると Bluetooth 接続が切れる機種があります。ダウンロード中は画面を消さない（設定 → ディスプレイ → 画面消灯時間を長めに）。
5. **手袋**: 設定 → ディスプレイ → 「タッチ感度を上げる」「手袋モード」（機種により名称が異なる）を ON。ボタンは大きく作ってあり、文字入力はサイト名以外ありません。
6. **寒さ**: スマホの電池は氷点下で急に減ります。内ポケットで温めておき、作業は接続 → 同期 → ダウンロード → 切断の順で短く。モバイルバッテリーがあると安心です。

### iPhone / iPad

iOS の Safari と Chrome は Web Bluetooth に対応していません（Apple の制限で、iOS 上のすべてのブラウザが同じです）。**App Store の「Bluefy – Web BLE Browser」**（無料、PNN Soft）を入れ、その中で https://0kam.github.io/SnowGauge/app/ を開いてください。

- Bluefy のブックマークに登録しておくと次回が楽です。ホーム画面アイコンからの起動（PWA）は Bluefy では使えないので、毎回 Bluefy を開きます。
- 圏外での動作は、Bluefy で一度オンラインで開いておけばキャッシュから起動します。ただし iOS はキャッシュを消すことがあるため、**出発前にオンラインで一度開く**ことを必ず行ってください。
- **CSV の保存は「共有して保存」から**。Bluefy はページからのダウンロードを保存できず、押しても何も起きません（エラーも出ません）。「ダウンロードして CSV 保存」で読み出したあと、下に出る**「共有して保存」→「ファイルに保存」**で「ファイル」アプリに入れてください。共有シートが出ないときは ▸「保存した CSV を画面で確認 / コピー / 別タブ」から**コピー**または**別タブで開く**。
- 手袋モードに相当する設定は iPhone にありません。タッチ対応手袋を使うか、作業中だけ外してください。

### 共通

- **接続できないとき**: 本体は 1〜2 秒ごとに電波を出しています。別のスマホが接続中だと見えません（同時接続は 1 台）。近づいて再検索してください。
- **切断前に「同期」**: 本体の時計はスマホから合わせます。未同期で切断しようとすると警告が出ます。
- **ライブ表示は必ず停止**: 照準合わせ中はセンサに約 120 mA 流れます。停止し忘れても切断か 5 分で自動停止します。
- **消去の前に CSV**: 「ダウンロードして CSV 保存」を押すまで消去ボタンは押せません。
- **画面が古い**: タブを閉じて開き直すと新しい版に切り替わります。「アプリ版」の日付で確認できます。
- **本体なしで練習**: https://0kam.github.io/SnowGauge/app/?demo=1 でサンプルデータ入りの画面を触れます（本体には何も送りません）。

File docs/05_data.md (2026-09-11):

# 05. データの見方

アプリ（04 章）で保存した CSV を、表計算ソフトや Python で読むための説明です。
列の正確な定義は [record_format.md](record_format.md) が正本です（ここでは重複させません）。

---

## 1. ファイルの名前と中身

### CSV（ふつうはこれだけ使う）

- ファイル名: **`<本体名>_<保存日時>.csv`**、例 `SG-3F2A_2026-12-31-03-15-20.csv`
  - 本体名 = Bluetooth に出る `SG-TFM-XXXX`（TFmini 版）/ `SG-TSD-XXXX`（TSD20 版）。旧ファームウェアは `SG-XXXX`。
  - 保存日時はスマホがファイルを作った時刻（**UTC**）です。観測時刻ではありません。
- 1 行目が見出し、2 行目以降が 1 観測 = 1 行。UTF-8（BOM 付き）・改行 CRLF。Excel でそのまま開けます。Mac の Excel は CSV を Shift_JIS として開くので、その場合はアプリ側で Shift_JIS 版を保存してください（[04_app.md](04_app.md) パネル 2 に実測表）。
- 列の並びと意味: [record_format.md の「CSV export」](record_format.md#csv-export-web-bluetooth-page-docsapp) を見てください。
- 本体に入っている**全期間**の記録が毎回入ります（消去しない限り、前回と同じ行がもう一度入ります → 第 5 節の重複除去）。

### 生データ（保険）

アプリの「生データ保存」で出るファイル:

- `<本体名>_rec_YYYYMM.bin` … 本体内のファイルそのもの。**月ごと（UTC の月）**に 1 ファイル、1 記録 = 40 バイト。
- `<本体名>_rec_notime.bin` … 時計が一度も合っていない間の記録（設置時に同期を忘れた場合など）。
- `<本体名>_site.json` … サイト名・緯度経度・タイムゾーンとその変更履歴。

---

## 2. 列の読み方（要点）

| 列 | 読み方 |
|---|---|
| `device_id`, `site_name`, `lat`, `lon`, `alt_m`, `tz_offset_min` | 本体名とサイト情報。**全行に同じ値が繰り返し**入っています（複数台をつなげるため） |
| `time_utc` | 観測時刻（UTC）。`2026-12-31T03:00:00Z` |
| `time_local` | 同じ時刻を現地時刻で。`2026-12-31T12:00:00+09:00`。`tz_offset_min`（分）を足したもの |
| `seq` | 本体内の通し番号。消去すると 1 から数え直し |
| `flags` | 本体が付けた印。`\|` 区切り（第 3 節） |
| `dist_cm` | **斜距離**の中央値（cm）。センサから雪面までの、センサの向きに沿った距離。有効値がないときは空 |
| `dist_var_cm2`, `strength`, `n_frames`, `n_valid`, `n_out_of_range` | 品質（第 4 節） |
| `tilt_deg` | センサ光軸の傾き（真下方向からの角度）。`pitch_deg` は基板面内（電池端子側へ +）、`roll_deg` は基板面外（部品面側へ +）の成分。基板は筐体内で鉛直（USB 左・センサ端子 J2 上）に取り付ける前提。定義と図は [coordinate_system.md](coordinate_system.md) |
| `imu_temp_c` | 基板上の温度。気温の目安（直射日光・筐体内なので参考値） |
| `lidar_temp_c` | 距離センサの**内部**温度。50〜75 °C は正常で、気温ではありません。TSD20 版は出力がないので空 |
| `vbat_start_mv`, `vbat_end_mv` | 電池電圧（mV）、センサ通電の直後と直前。`end` の方が負荷時。4400 未満は交換時期 |
| `d0_cm`, `theta0_deg` | 基準値（設置時の ZERO または積雪深入力で本体に保存されたもの） |
| `snow_depth_cm` | **積雪深** = `(d0_cm − dist_cm) × cos(tilt_deg)`。基準値がない・距離がないときは空 |

> **注意**: `d0_cm` と `snow_depth_cm` は、**ダウンロードした時点で本体に入っていた基準値**を全行に当てはめて計算しています。途中で基準を取り直した場合、それより前の行の積雪深は正しくありません。第 6 節の方法で計算し直してください。

---

## 3. `flags` 列の意味

| 値 | 意味 |
|---|---|
| `time_synced` | 起動後に時刻合わせ済み。時刻はそのまま信用できる |
| `time_estimated` | 再起動後、まだ同期していない（第 7 節）。時刻は遅れている可能性がある |
| （どちらもなく `time_utc` が空） | 時計が一度も合っていない。順番だけ正しい |
| `lidar_ok` | 距離の有効値が 1 つ以上ある |
| `tilt_ok` | 傾斜センサが読めた |
| `manual` | 自動観測ではなく、シェルや BLE から手動で測ったもの。解析からは除くのが普通 |
| `first_after_boot` | 再起動（電池交換など）後の最初の記録。区切りの目印 |
| `sensor_tsd20` | TSD20 版の本体が書いた記録（付いていなければ TFmini Plus 版）。この記録では `strength` は常に 0、`lidar_temp_c` は空 |

---

## 4. 品質の列と、アプリの「要確認」

本体は 1 回の観測で距離センサを 100 回（`n_frames`）読み、そのうち使える回（`n_valid`）の中央値を `dist_cm`、ばらつき（分散）を `dist_var_cm2` にしています。`n_out_of_range` は「測れない」「信号が弱い」「飽和」と返ってきた回数です。

アプリの「要確認」欄と同じ基準で行を選り分けるなら:

| 条件 | アプリの表示 | 扱い |
|---|---|---|
| `dist_cm` が空 | 測距なし | 欠測扱い |
| `n_valid < n_frames × 0.5` | 有効率低 | 降雪・霧・汚れ。要注意 |
| `dist_var_cm2 > 4` | ばらつき大 | 降雪中・揺れ。中央値は使えることが多い |
| `n_out_of_range > n_frames × 0.5` | レンジ外多 | 欠測に近い |
| `flags` に `time_synced` がない | 時刻推定 / 時刻なし | 第 7 節 |
| 前の行との間隔が観測間隔の 1.5 倍超（`manual` 以外） | 欠測あり | 電池・再起動 |
| `vbat_end_mv < 4400` | 電池低 | 交換時期。通電直後の電圧（`vbat_start_mv`）が 4600 未満だと本体は距離測定を止める |

`strength`（信号強度）は 100 未満だとセンサの仕様上信頼できず、65535 は飽和です。雪面では通常数百〜数千です。TSD20 版（`sensor_tsd20` フラグ）には信号強度がなく常に 0 なので、品質は `n_valid`/`n_out_of_range` と `dist_var_cm2` だけで判断します。

---

## 5. 複数台・複数回のファイルをつなげる

サイト情報の列が全行に入っているので、そのまま縦につなげられます。**同じ本体を消去せずに何度も回収すると同じ記録が重複する**ので、`device_id` + `time_utc` + `seq` で重複を落とします。

```python
import glob, pandas as pd
df = pd.concat(pd.read_csv(f) for f in glob.glob("SG-*.csv"))
df["time_local"] = pd.to_datetime(df["time_local"], utc=True).dt.tz_convert("Asia/Tokyo")
df = df.drop_duplicates(["device_id", "time_utc", "seq"]).sort_values(["device_id", "time_utc"])
df = df[~df["flags"].fillna("").str.contains("manual")]          # 手動測定を除く
```

`df.groupby("device_id")["snow_depth_cm"].plot()` などで台ごとに描けます。

---

## 6. 別の基準値で積雪深を計算し直す

CSV には生の `dist_cm` と `tilt_deg` が残っているので、基準値を変えて計算し直せます。

```
snow_depth_cm = (d0_new − dist_cm) × cos(tilt_deg [度])
```

- **無雪期の値から d0 を決め直す**: 雪のない日の `dist_cm` の中央値を `d0_new` にする（もっとも確実な方法）。
- **設置時にプローブで測った積雪深 `h` から**: そのときの行の `dist_cm` = `d`、`tilt_deg` = `t` を使って `d0_new = d + h / cos(t)`（本体の「積雪深で基準設定」と同じ式）。
- 基準を取り直した日時は `theta0_deg` の隣にはなく、アプリのパネル 3「基準設定日時」に出ます。取り直したら野帳に控えてください。

```python
import numpy as np
d0_new = 245.0
df["snow_depth_cm"] = (d0_new - df["dist_cm"]) * np.cos(np.radians(df["tilt_deg"]))
```

`tilt_deg` が設置時（`theta0_deg`）から大きく変わっている行は、ポールが傾いた可能性があります。

---

## 7. 時刻の列と `time_estimated`

- 本体の時計は **UTC** で動き、`time_utc` はその値です。`time_local` は本体に保存されたタイムゾーン（`tz_offset_min`、同期時にスマホから自動設定）で表示し直しただけです。
- 本体は電池を外すと時計を失います。次に電源が入ると、**最後の記録の時刻から**時計を再開し、次に同期されるまでの記録に `time_estimated` を付けます。この間の時刻は「間隔は正しいが、全体が遅れている」状態です（電源が切れていた時間の分だけ遅れます）。
- 直し方: `time_estimated` の区間の直後にある最初の `time_synced` の行（巡回で同期した直後の記録）を基準に、観測間隔を逆算して埋め直すのが実用的です。`first_after_boot` が再起動の位置を示します。厳密には遅れの量は分からないので、この区間は「時刻は概算」と注記して扱ってください。
- 巡回のたびにアプリで「同期」を押していれば、この区間は再起動から次の巡回までの間だけです。

---

## 8. 生データ（.bin）から CSV を作る

アプリの CSV が使えないとき（消してしまった、壊れた）、「生データ保存」の `.bin` から Python で復元できます。

```bash
python3 tools/decode_records.py SG-3F2A_rec_202612.bin SG-3F2A_rec_202701.bin > records.csv
```

- 列は `seq, epoch, time_utc, flags, dist_cm, var_cm2, strength, n_frames, n_valid, n_oor, tilt_deg, pitch_deg, roll_deg, imu_temp_c, lidar_temp_c, vbat_start_mv, vbat_end_mv`。**サイト情報・現地時刻・積雪深の列はありません**（第 6 節の式で計算、サイト情報は `site.json` を見る）。
- 壊れた記録は飛ばして、標準エラー出力に件数が出ます。
- USB シェル（03 章）で `rec hex 5` と打って出た 16 進の行を `--hex "…"` に渡すと、1 件ずつ復元することもできます。USB で全件を文字として吸い出すなら `python3 tools/sgshell.py --file dump.txt "rec dump 0"`（pyserial が必要）。

## 補足: タイムゾーン列

`time_local` と `tz_offset_min` は本体に保存されたタイムゾーン設定から作られます。アプリで一度も「同期」していない本体は既定の +09:00（540 分）です。海外や別のタイムゾーンで使うときは、現地でスマホから同期すると自動で更新されます。

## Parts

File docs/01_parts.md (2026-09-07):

# 01. 部品購入（SnowGauge 部品表 / BOM）

対象: **PCB v1.2**（TFmini Plus 版・TSD20 版共通基板）および同一トポロジの**ブレッドボード版**。
読者: 電子工作が初めての学生。型番・ファイル名は英語のままにしてあります。

> **この表が BOM の唯一の正です。**
> 設計仕様書 §6 は設計根拠の記録です（v0.12 で v1.2 の数量に修正済み、最新は v0.13）。購入数量はこのページの表に従ってください。
> 電気的なつながり（どのピンに何が付くか）の正は [pcb/README.md](../pcb/README.md) です。

[^spec6]: 資料間で食い違いがある場合は pcb/README.md > docs/gen_breadboard.py の PARTS > 設計仕様書 の順に優先しています（CLAUDE.md の取り決め）。

## 1. 買い方の目安

| 作るもの | 必要な表 |
|---|---|
| ブレッドボード版（PCB が届くまでの開発用） | (a) 共通部品 + (c) ブレッドボード消耗品 |
| PCB v1.2 版（TFmini Plus） | (a) 共通部品 + (b) PCB 追加部品 |
| PCB v1.2 版（TSD20） | (a) の TFmini Plus と U2=F50 を (d) の部品に置き換え + (b) |

秋月電子は 1 パック 10 本／100 本売りの部品が多いので、「数量」欄は**回路 1 台に載る個数**、「備考」に販売単位を書いています。複数台作るときは台数を掛けてください。
注文用の CSV（同じ内容）: [01_parts.csv](01_parts.csv)

## 2. 部品表

### (a) 共通部品（1 台分）

| 記号 | 部品 | 値/型番 | 数量 | 購入先リンク | 備考 |
|---|---|---|---|---|---|
| A1 | マイコン（IMU・温度・BLE・2 MB QSPI 内蔵） | Seeed **XIAO nRF52840 Sense** | 1 | [スイッチサイエンス 8146](https://www.switch-science.com/products/8146) | ~¥3,000。展開台数 +2〜3 台の予備を推奨（仕様書 §6） |
| — | LiDAR（上位側） | Benewake **TFmini Plus** | 1 | [スイッチサイエンス 8153](https://www.switch-science.com/products/8153) | ~¥7,000〜9,000。IP65。付属ケーブル: 赤=+5V / 黒=GND / 緑=TX / 白=RX（現物の説明書で要確認） |
| U1 | 3.3 V LDO（常時 ON） | **NJU7223F33**（TO-220F, 500 mA） | 1 | [秋月 100432](https://akizukidenshi.com/catalog/g/g100432/) | ¥80。ピン並び VOUT-VIN-GND |
| U2 | 5 V LDO（測定時のみ ON） | **NJU7223F50**（TO-220F, 500 mA） | 1 | [秋月 100671](https://akizukidenshi.com/catalog/g/g100671/) | ¥50〜80。U1 と同じピン並び。TSD20 版は F33 に置き換え → (d) |
| Q1 | 高側スイッチ P-ch MOSFET | **2SJ334**（TO-220） | 1 | [秋月 102846](https://akizukidenshi.com/catalog/g/g102846/) | ¥110。ピン並び G-D-S |
| Q2 | ゲート駆動 N-ch MOSFET | **2SK4017**（TO-251） | **1** | [秋月 107597](https://akizukidenshi.com/catalog/g/g107597/) | ¥30。ピン並び G-D-S。v1.2 では Q2 の 1 個のみ（Q3 は廃止） |
| D1 | 逆接保護ショットキー | **1N5819**（40 V / 1 A） | 1 | [秋月 117244](https://akizukidenshi.com/catalog/g/g117244/) | ¥100 / 10 本入り。帯（カソード）側が VBAT |
| C1, C2, C3, C5 | セラミックコンデンサ（パスコン） | **0.1 µF** X7R 50 V | **4** | [秋月 113582](https://akizukidenshi.com/catalog/g/g113582/) | ¥100 / 10 個入り。U1・U2 の入出力に各 1 |
| C4 | バルクコンデンサ（5 V レール） | **OS-CON SEPC 470 µF / 16 V** | 1 | [秋月 108292](https://akizukidenshi.com/catalog/g/g108292/) | ~¥200。極性あり（長い足が +）。−55 ℃対応の固体高分子。PCB では φ10 mm・5 mm ピッチ |
| C6 | セラミックコンデンサ（3.3 V レール） | **10 µF**（積層セラミック、極性なし） | 1 | [秋月 102216](https://akizukidenshi.com/catalog/g/g102216/) | PCB は **5 mm リードピッチ**の足付き品（2.5 mm ピッチ品は足を広げれば可）。ブレッドボードは何でも可 |
| R1, R2 | 電池電圧の分圧 | **1 MΩ** 1/4 W カーボン | 2 | [秋月 125105](https://akizukidenshi.com/catalog/g/g125105/) | ¥120 / 100 本入り。代替: 同じ値なら 5 kΩ〜1 MΩ のどれでも（§4） |
| R3 | Q2 ゲート直列 | **10 kΩ** 1/4 W | 1 | [秋月 125103](https://akizukidenshi.com/catalog/g/g125103/) | ¥120 / 100 本入り。代替: 150 Ω〜2.2 kΩ（§4） |
| R4, R5 | Q2 ゲートプルダウン / Q1 G-S プルアップ | **100 kΩ** 1/4 W | **2** | [秋月 125104](https://akizukidenshi.com/catalog/g/g125104/) | R4・R5 の 2 本（R6 は v1.2 で廃止）。代替: 10 kΩ 可（§4） |
| R7 | UART TX 直列（保護） | **1 kΩ** 1/4 W | 1 | [秋月 125102](https://akizukidenshi.com/catalog/g/g125102/) | ¥120 / 100 本入り。代替: 1 k〜5 kΩ（§4） |
| BT | 電池 | 単3 リチウム（Energizer Ultimate Lithium **L91** = LAA4PKJP 等、Panasonic **FR6HJ/4B** など） | 4 | 家電量販店・通販 | 開放 7.2 V → 終止 4.0 V、≈21 Wh。低温・自己放電特性で最良（仕様書 §6） |
| — | 電池ボックス | 単3 ×4 直列（スナップ式）＋ スナップ（リード線付き） | 各 1 | ボックス [秋月 101972](https://akizukidenshi.com/catalog/g/g101972/)、スナップ [秋月 102662](https://akizukidenshi.com/catalog/g/g102662/) | PCB では赤線を J1 の「+」、黒線を「−」へ。ブレッドボードでは線を直接挿す |

### (b) PCB v1.2 追加部品（基板に載せる分。出典 pcb/README.md）

| 記号 | 部品 | 値/型番 | 数量 | 購入先リンク | 備考 |
|---|---|---|---|---|---|
| — | プリント基板 | SnowGauge PCB v1.2（64 × 50 mm, 2 層） | 1 | JLCPCB（[pcb/SnowGauge_v1.2_gerbers.zip](../pcb/SnowGauge_v1.2_gerbers.zip) をアップロード） | 最小 5 枚。注文手順は [02_assembly.md](02_assembly.md) §B |
| J1, J2 | ネジ端子台 2P | **5.08 mm ピッチ・連結型**（TB111-2 / MKDS-1,5 系） | **3** | [秋月 102333](https://akizukidenshi.com/catalog/g/g102333/) | J1 = 電池（1 個）。J2 = 2 個をスライドして連結し 4 極にする（TFmini 用） |
| A1 ソケット | ピンソケット 1×7（2.54 mm、低背） | メス 1×7 | 2 | [秋月 104285](https://akizukidenshi.com/catalog/g/g104285/) | XIAO を差し替え可能にする。基板穴 0.89 mm: 丸ピン加工品や一般的な板ピン品は可、**0.64 mm 角ピンの製品は避ける** |
| J3 | ピンヘッダ 1×4（2.54 mm） | オス 1×4 | 1 | [秋月 100167](https://akizukidenshi.com/catalog/g/g100167/)（40P を折って使う） | 予備 I2C（SCL / SDA / GND / 3V3）。使わなければ省略可 |
| H1〜H4 | M3 ネジ・スペーサ | M3（基板穴 φ3.2） | 4 | 一般的なもの（筐体に合わせて長さを選ぶ） | 四隅、穴中心間 57 × 43 mm |
| C6 | （再掲）10 µF 積セラ | **5 mm ピッチ** | 1 | [秋月 102216](https://akizukidenshi.com/catalog/g/g102216/) | (a) の C6 と同一部品。PCB 用はピッチに注意 |

### (c) ブレッドボード版の消耗品

| 記号 | 部品 | 値/型番 | 数量 | 購入先リンク | 備考 |
|---|---|---|---|---|---|
| — | ブレッドボード | **830 穴**（a〜j 行 × 63 列、上下に電源レール） | 1 | 一般的なもの | 配線図 [breadboard_guide.html](https://0kam.github.io/SnowGauge/breadboard_guide.html) はこのサイズ前提 |
| — | ジャンパワイヤ | 単線ジャンパ（各色）+ オス–オス ジャンパ数本 | 1 セット | 一般的なもの | 電源系は**短く太いもの**（TFmini 起動時ピーク 500 mA） |
| — | 電源 | 安定化電源（6.0 V、電流制限 **1 A 以上**）または (a) の電池ボックス + L91 ×4 | 1 | 一般的なもの | 開発中は安定化電源が便利。スリープ電流は電池と直列の µA 電流計で測る |
| — | TFmini 接続補助 | ピンヘッダ付きジャンパ、または線先に圧着するピン | 適量 | 一般的なもの | TFmini の線は細く抜けやすい |
| — | テスター（デジタルマルチメータ） | DC 電圧が 0.01 V 単位で読めるもの | 1 | 一般的なもの | 各 STEP の確認に必須 |

### (d) TSD20 版（廉価 LiDAR）で変わる部品

基板・配線は TFmini Plus 版と完全に同じで、**U2 を差し替えるだけ**です（センサレールが 5 V → 3.3 V になる）。

| 記号 | 部品 | 値/型番 | 数量 | 購入先リンク | 備考 |
|---|---|---|---|---|---|
| — | LiDAR（廉価側） | PONO **TSD20** | 1 | [秋月 131304](https://akizukidenshi.com/catalog/g/g131304/) | ¥2,580。8 m@100 kLux、3.3 V 駆動、UART/I2C。TFmini Plus の代わりに使う |
| U2 | 3.3 V LDO（測定時のみ ON） | **NJU7223F33**（2 個目） | 1 | [秋月 100432](https://akizukidenshi.com/catalog/g/g100432/) | NJU7223F50 の代わり。基板シルク「U2: F50=TFmini / F33=TSD20」 |

注意: TSD20 用ファームウェアは TFmini 版とは**別ビルド**です（`firmware/overlay-tsd20.conf`、BLE 名が `ST-XXXX` になる。[docs/03_firmware.md](03_firmware.md)）。TSD20 のリード線はコネクタ側で左から 白・赤・黄・緑・水色・黒 = ピン 1〜6（**赤 = 3.3 V、黄 = TX、緑 = RX、黒 = GND**、白・水色 = NC。手持ち品で確認）（[tsd20_protocol.md](tsd20_protocol.md)、ブレッドボードは [breadboard_guide_tsd20.html](https://0kam.github.io/SnowGauge/breadboard_guide_tsd20.html)）。**逆接・過電圧保護がない**ので、U2 が F33 になっていることを確認してからつなぐこと。

## 3. 概算（1 台）

- TFmini Plus 版（PCB）: 約 ¥12,000（XIAO ~¥3,000 + TFmini ~¥8,000 + その他 ~¥1,500、基板・電池は別）
- TSD20 版（PCB）: 約 ¥7,000（TFmini → TSD20 ¥2,580）
- 仕様書 §6 の概算（TFmini 構成 ~¥12,000〜14,000、TSD20 構成 ~¥8,000、いずれも電池・筐体込み）とは含める範囲が異なります。ここでは電池 L91 ×4 と基板代（JLCPCB 5 枚 + 速達送料）を含みません。

## 4. 値の代替について（手持ち部品で組むとき）

出典: docs/gen_breadboard.py（ブレッドボード配線図 §4「注意メモ」）。実際に組んで検証済みのブレッドボードは R3=150 Ω、R4=R5=10 kΩ、R1=R2=5 kΩ、R7=2.2 kΩ で動いています（docs/measurements/2026-09-03_breadboard_current.md）。

| 記号 | 公称値 | 許される代替 | 理由・条件 |
|---|---|---|---|
| R3 | 10 kΩ | **150 Ω〜2.2 kΩ**（10 kΩ も可） | R3 と R4 の分圧で Q2 のゲート電圧が **2.7 V 以上**になること。**R3 = R4 = 10 kΩ は NG**（ゲートが 1.65 V にしかならず Q2 が ON しきれない） |
| R4, R5 | 100 kΩ | **10 kΩ** 可 | R4 = Q2 のプルダウン、R5 = Q1 の G-S プルアップ。R3 を小さくしたときは上の条件を R4 と合わせて確認 |
| R1, R2 | 1 MΩ | **同じ値なら 5 kΩ〜1 MΩ のどれでも** | ファームウェアは「読み値 ×2」で電池電圧を出すので、2 本が同じ値であればよい。分圧は VBAT_SW（スイッチ後）にぶら下がるのでスリープ電流には影響しない |
| R7 | 1 kΩ | **1 k〜5 kΩ** | UART TX の直列保護（幽霊給電・短絡対策） |
| C6 | 10 µF | 4.7〜22 µF 程度の積セラ | 3.3 V レールの平滑。極性なし |
| C1, C2, C3, C5 | 0.1 µF | 変更しない | NJU7223 の入出力に指定されている値 |
| C4 | OS-CON 470 µF | 変更しない（アルミ電解は不可） | 低温で ESR が上がらないことが要件（−55 ℃対応） |

ブレッドボードで組んだ回路と PCB は同じトポロジなので、ここで動いた代替値はそのまま PCB でも使えます。ただし**最終評価（スリープ電流など）は公称値で組んだ PCB で行う**方針です。

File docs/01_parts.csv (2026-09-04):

区分 | 記号 | 部品 | 値/型番 | 数量 | 購入先リンク | 備考
共通 | A1 | マイコン（IMU・温度・BLE・2MB QSPI内蔵） | Seeed XIAO nRF52840 Sense | 1 | https://www.switch-science.com/products/8146 | ~¥3000。展開台数+2〜3台の予備を推奨
共通 | - | LiDAR（上位側） | Benewake TFmini Plus | 1 | https://www.switch-science.com/products/8153 | ~¥7000〜9000。IP65。ケーブル 赤=+5V/黒=GND/緑=TX/白=RX（現物で要確認）
共通 | U1 | 3.3V LDO（常時ON） | NJU7223F33 (TO-220F 500mA) | 1 | https://akizukidenshi.com/catalog/g/g100432/ | ¥80。ピン並び VOUT-VIN-GND
共通 | U2 | 5V LDO（測定時のみON） | NJU7223F50 (TO-220F 500mA) | 1 | https://akizukidenshi.com/catalog/g/g100671/ | ¥50〜80。TSD20版はF33に置き換え
共通 | Q1 | 高側スイッチ P-ch MOSFET | 2SJ334 (TO-220) | 1 | https://akizukidenshi.com/catalog/g/g102846/ | ¥110。ピン並び G-D-S
共通 | Q2 | ゲート駆動 N-ch MOSFET | 2SK4017 (TO-251) | 1 | https://akizukidenshi.com/catalog/g/g107597/ | ¥30。ピン並び G-D-S。v1.2ではQ2の1個のみ（Q3廃止）
共通 | D1 | 逆接保護ショットキー | 1N5819 (40V/1A) | 1 | https://akizukidenshi.com/catalog/g/g117244/ | ¥100/10本入り。帯（カソード）側がVBAT
共通 | C1,C2,C3,C5 | セラミックコンデンサ（パスコン） | 0.1µF X7R 50V | 4 | https://akizukidenshi.com/catalog/g/g113582/ | ¥100/10個入り
共通 | C4 | バルクコンデンサ（5Vレール） | OS-CON SEPC 470µF/16V | 1 | https://akizukidenshi.com/catalog/g/g108292/ | ~¥200。極性あり（長い足が+）。PCBはφ10mm・5mmピッチ
共通 | C6 | セラミックコンデンサ（3.3Vレール） | 10µF 積層セラミック（極性なし） | 1 | https://akizukidenshi.com/catalog/g/g102216/ | PCBは5mmリードピッチ品（2.5mmは足を広げる）
共通 | R1,R2 | 電池電圧の分圧 | 1MΩ 1/4W カーボン | 2 | https://akizukidenshi.com/catalog/g/g125105/ | ¥120/100本入り。代替: 同じ値なら5kΩ〜1MΩ
共通 | R3 | Q2ゲート直列 | 10kΩ 1/4W | 1 | https://akizukidenshi.com/catalog/g/g125103/ | ¥120/100本入り。代替: 150Ω〜2.2kΩ（R3=R4=10kはNG）
共通 | R4,R5 | Q2プルダウン / Q1 G-Sプルアップ | 100kΩ 1/4W | 2 | https://akizukidenshi.com/catalog/g/g125104/ | R4・R5の2本（R6廃止）。代替: 10kΩ可
共通 | R7 | UART TX直列（保護） | 1kΩ 1/4W | 1 | https://akizukidenshi.com/catalog/g/g125102/ | ¥120/100本入り。代替: 1k〜5kΩ
共通 | BT | 電池 | 単3リチウム（Energizer L91=LAA4PKJP / Panasonic FR6HJ/4B など） | 4 | 家電量販店・通販 | 開放7.2V→終止4.0V。低温特性で最良
共通 | - | 電池ボックス | 単3×4 直列 スナップ式 + スナップ | 各1 | https://akizukidenshi.com/catalog/g/g101972/ https://akizukidenshi.com/catalog/g/g102662/ | PCBでは赤→J1「+」、黒→J1「−」
PCB v1.2 | - | プリント基板 | SnowGauge PCB v1.2 (64x50mm 2層) | 1 | JLCPCB（pcb/SnowGauge_v1.2_gerbers.zip） | 最小5枚。02_assembly.md §B参照
PCB v1.2 | J1,J2 | ネジ端子台 2P | 5.08mmピッチ 連結型 (TB111-2 / MKDS-1.5系) | 3 | https://akizukidenshi.com/catalog/g/g102333/ | J1=電池。J2=2個を連結して4極（TFmini）
PCB v1.2 | A1ソケット | ピンソケット 1x7 2.54mm 低背 | メス 1x7 | 2 | https://akizukidenshi.com/catalog/g/g104285/ | 基板穴0.89mm。0.64mm角ピン品は避ける
PCB v1.2 | J3 | ピンヘッダ 1x4 2.54mm | オス 1x4 | 1 | https://akizukidenshi.com/catalog/g/g100167/ | 予備I2C。省略可
PCB v1.2 | H1-H4 | M3ネジ・スペーサ | M3（穴φ3.2） | 4 | 一般的なもの | 四隅 穴中心間57x43mm
ブレッドボード | - | ブレッドボード | 830穴 | 1 | 一般的なもの | breadboard_guide.htmlはこのサイズ前提
ブレッドボード | - | ジャンパワイヤ | 単線ジャンパ各色 + オス-オス数本 | 1セット | 一般的なもの | 電源系は短く太いもの
ブレッドボード | - | 電源 | 安定化電源 6.0V 電流制限1A以上 または 電池ボックス+L91x4 | 1 | 一般的なもの | スリープ電流測定は電池と直列のµA電流計
ブレッドボード | - | TFmini接続補助 | ピンヘッダ付きジャンパ または 圧着ピン | 適量 | 一般的なもの | TFminiの線は細く抜けやすい
ブレッドボード | - | テスター | DC電圧 0.01V単位 | 1 | 一般的なもの | 各STEPの確認に必須
TSD20版 | - | LiDAR（廉価側） | PONO TSD20 | 1 | https://akizukidenshi.com/catalog/g/g131304/ | ¥2580。TFmini Plusの代わり。FW未作成
TSD20版 | U2 | 3.3V LDO（測定時のみON） | NJU7223F33（2個目） | 1 | https://akizukidenshi.com/catalog/g/g100432/ | NJU7223F50の代わり

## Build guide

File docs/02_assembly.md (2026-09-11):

# 02. 組み立て

対象: SnowGauge **PCB v1.2**（TFmini Plus 版 / TSD20 版共通）と、同じ回路をはんだ付けなしで組む**ブレッドボード版**。
部品は [01_parts.md](01_parts.md) の表で揃えてください。ピン配置・回路のつながりの正は [pcb/README.md](../pcb/README.md) です。

読み順: **A. ブレッドボード**（PCB が届く前の開発・練習用）→ **B. PCB v1.2** → **C. 筐体・設置**（検討中）

---

## A. ブレッドボード版

### A-1. 何のために作るか

- PCB が届くまでの間に、ファームウェアの開発と動作確認をするための試作です。
- 回路は **PCB v1.2 と同一トポロジ**（電池電圧の分圧はスイッチ後のレール VBAT_SW に接続、Q3・R6・D3 は無し）。ここで動いたファームウェアは、そのまま PCB でも動きます。
- 学生の組み立て会では、はんだ付け前に回路を理解する練習台にもなります。

### A-2. 配線図（生成物）

**https://0kam.github.io/SnowGauge/breadboard_guide.html**

- 830 穴ブレッドボード 1 枚とジャンパワイヤで組めます。全体図 + STEP ごとの拡大図、各部品の両端の穴名（例 `c10`）、チェックリストが載っています。
- この HTML は `docs/gen_breadboard.py` が生成します。**手で編集しないでください**（直すときはスクリプトの `PARTS` を直して再生成）。
- XIAO は **USB コネクタを左**に向けて挿します。このとき
  上の列（e20〜e26）= `5V, GND, 3V3, D10, D9, D8, D7`、
  下の列（f20〜f26）= `D0/A0, D1, D2, D3, D4, D5, D6` です。逆向きに挿すと壊れるので、挿す前に指差し確認。

### A-3. ベンチでの約束（必読）

電源は「XIAO の USB」と「電池／安定化電源」の 2 系統があります。ジャンパ **⑩**（橙、`a10 → a22`、U1 の 3.3 V 出力 → XIAO の 3V3 ピン）が両者をつなぐ線です。

| したいこと | USB | 電池／安定化電源 | ジャンパ ⑩ |
|---|---|---|---|
| ファームウェアの書き込み・シェル操作 | 挿す | 外す（または ⑩ を抜いて併用） | **抜く** |
| USB でシェルを見ながらセンサ側を電池で動かす | 挿す | 入れる | **抜く**（XIAO は USB 給電、センサレールと分圧は電池給電。GND は共通のまま） |
| スリープ電流の測定・実運用の模擬 | **外す** | 入れる | 挿す |

- **⑩ を挿したまま USB と電池（安定化電源）を同時につないではいけません**（3V3 ピンへの外部給電と USB 給電がぶつかります）。
- 安定化電源で電池を代用するときは **6.0 V、電流制限 1 A 以上**（TFmini の起動時ピークは 500 mA）。
- 電源系のジャンパは短く太いものを使う（TFmini の突入電流でブレッドボードの接触抵抗が効く）。
- スリープ電流の最終評価は PCB で行います（ブレッドボードは接触・リークで数 µA 上振れします）。

### A-4. STEP 1〜5 の確認（要約）

各 STEP を組み終えたら、**テスターで下の値を確認してから次へ**。詳しい穴名は配線図のチェックリストを参照。

| STEP | 組むもの | 確認すること（テスターの黒棒は青レール = GND） |
|---|---|---|
| 1 | 電源部（D1、U1、C1/C2/C6） | 赤レール = 電池電圧 −0.2〜0.4 V。`c10`（U1 の OUT）= **3.25〜3.35 V** |
| 2 | XIAO と 3.3 V / GND のジャンパ | XIAO の 3V3 ピン（22 列）− GND ピン（21 列）= **3.3 V**（LED は点きません） |
| 3 | スイッチ（Q2・Q1）と 5 V 系（U2、C3/C4/C5） | 何もしないとき `e42`（5 V ノード）= **0 V**。ジャンパで `a28`（Q2 の G）を 3.3 V（`c10`）に触れさせると `e42` = **4.9〜5.1 V**、離すと 0 V。触れている間 `a32`（Q1 の G）≈ 0 V、`a33`（VBAT_SW）= 電池電圧 |
| 4 | 電池電圧の分圧（R1/R2 → A0） | `a28` を 3.3 V に触れさせている間 `a36`（分圧の中点）= **電池電圧のほぼ半分**。離すと **0 V** |
| 5 | TFmini（R7、4 本の線） | テスト FW で `rail on` → `tfmini raw 500` で距離フレームが届く。`rail off` → `e42` = 0 V。電池と直列の µA 電流計でスリープ **90 µA 以下** |

STEP 5 の TFmini の線: 赤 = +5 V（`e42`）、黒 = GND、緑 = TX → XIAO D7、白 = RX ← R7 ← XIAO D6。
実測（2026-09-03）: スリープ約 17〜18 µA、BLE アドバタイズ込みで約 26 µA（[measurements/2026-09-03_breadboard_current.md](measurements/2026-09-03_breadboard_current.md)）。

---

## B. PCB v1.2

### B-1. 基板の注文（JLCPCB、日本まで約 1 週間）

1. https://jlcpcb.com → 「Add gerber file」→ [pcb/SnowGauge_v1.2_gerbers.zip](../pcb/SnowGauge_v1.2_gerbers.zip) をアップロード
2. 設定: 2 層、64 × 50 mm（自動認識）、枚数 5（または 10）、厚さ 1.6 mm、HASL、緑 — **すべて既定値のままで可**
3. 配送: **DHL または OCS Express**（3〜4 日で届く。エコノミー便は数週間かかる）

基板の概要: 64 × 50 mm、2 層、部品はすべてリード部品（スルーホール）。裏面は GND ベタ。四隅に M3 穴（中心間 57 × 43 mm）。電池端子 J1 は下辺、TFmini 端子 J2 は右辺に出ます。

### B-2. 部品配置と向き

基板のシルク（白い印刷）に記号が書いてあります。**向きのある部品**は特に注意。

#### レギュレータ（U1・U2）と MOSFET（Q1・Q2）の前後

シルクに `U1` `Q1` `U2` `Q2` と書いてある側が**金属タブ（背面）**で、**型番の印字面はその反対側**を向きます。基板を「SnowGauge v1.2」の文字が上、電池端子 J1 が下になるように置いたとき:

| 記号 | 金属タブ（記号シルクのある側） | 型番の印字面が向く方向 |
|---|---|---|
| U1 | 上辺側（「SnowGauge v1.2」の側） | **下**（XIAO・J1 側） |
| Q1 | 上辺側 | **下**（XIAO 側） |
| U2 | 下側（C3・C4 のある基板内側） | **上**（上辺側） |
| Q2 | 下側（C6 側） | **上**（XIAO 側） |

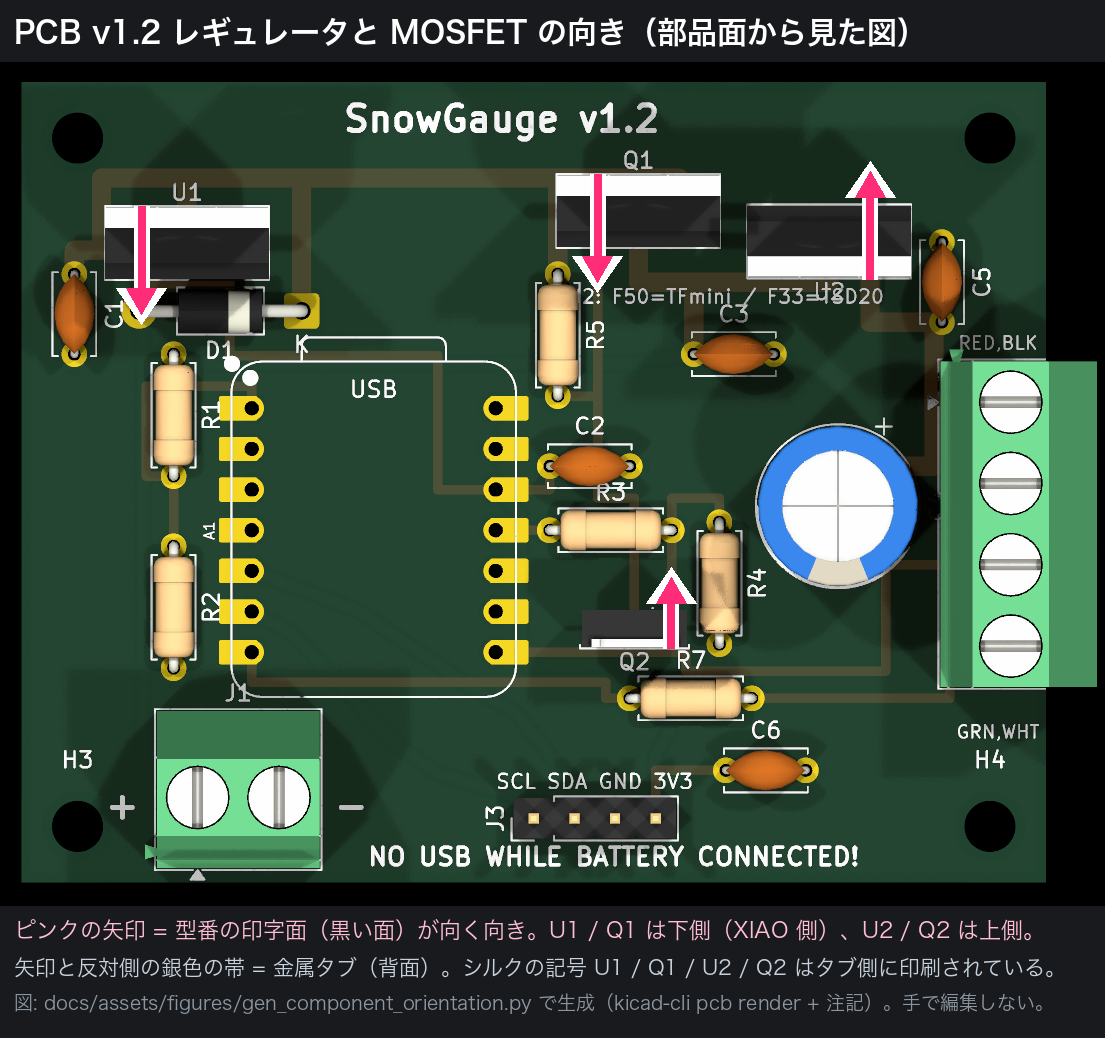
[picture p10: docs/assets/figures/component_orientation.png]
レギュレータと MOSFET の向き


見分け方: TO-220 の外形シルクは片方の長辺だけ**幅 1.4 mm の細い帯（中に切れ目 2 本）**になっていて、そこがタブ側です。U1・U2 は TO-220F（フルモールド）で両面とも樹脂なので、**型番が印刷されている面が前**と覚えます。印字面を上表の向きにすれば、下表のピン並びは自動的に合います（逆に、印字面を見ながらデータシート通りのピン並びで挿せば、タブは自然に記号シルクの側を向きます）。

| 記号 | 部品 | 向き・注意 |
|---|---|---|
| D1 | 1N5819 | 帯（カソード）をシルクの **「K」** 側に。帯側が VBAT（回路の内側）、反対側が電池 + |
| U1 | NJU7223F33（3.3 V、常時） | TO-220F。**型番の印字面を下（XIAO 側）に向ける**（タブは上辺側）。印字面から見て左から **VOUT – VIN – GND** |
| U2 | NJU7223F50（TFmini 版）/ NJU7223F33（TSD20 版） | **U1 と前後が逆。印字面を上（上辺側）に向ける**（タブは下側）。ピン並びは U1 と同じで、印字面から見て左から **VOUT – VIN – GND**。シルク「U2: F50=TFmini / F33=TSD20」。型番の印字で読み分ける |
| Q1 | 2SJ334（P-ch、TO-220） | **印字面を下（XIAO 側）に向ける**（タブは上辺側）。印字面から見て左から **G – D – S** |
| Q2 | 2SK4017（N-ch、TO-251、小さい方） | **印字面を上（XIAO 側）に向ける**（タブは下側）。印字面から見て左から **G – D – S** |
| R1, R2 | 1 MΩ | 向きなし。分圧（VBAT_SW → A0） |
| R3 | 10 kΩ | 向きなし。D10（SENSOR_EN）→ Q2 ゲート |
| R4, R5 | 100 kΩ | 向きなし。R4 = Q2 ゲートプルダウン、R5 = Q1 の G-S プルアップ |
| R7 | 1 kΩ | 向きなし。D6（TX）→ TFmini 白 |
| C1, C2, C3, C5 | 0.1 µF | 向きなし。U1・U2 の入出力のすぐそば |
| C6 | 10 µF（5 mm ピッチ） | 向きなし。3.3 V レール |
| C4 | OS-CON 470 µF / 16 V | **極性あり**。長い足 = **+** をシルクの「+」側（5 V レール）へ。反対側が GND |
| J1 | 端子台 2P（5.08 mm） | 線の差し込み口を**基板の外（下辺）**へ向ける。シルク「+」「−」 |
| J2 | 端子台 2P × 2（連結して 4 極） | 2 個をスライドして 1 つにしてから差す。差し込み口を**右辺の外**へ。上から **RED(+5V) / BLK(GND) / GRN(TX) / WHT(RX)**（シルク「RED,BLK」「GRN,WHT」） |
| J3 | ピンヘッダ 1×4 | シルク「SCL SDA GND 3V3」。予備 I2C。省略可 |
| A1 | XIAO 用ピンソケット 1×7 × 2 | ソケットを 2 列はんだ付けし、XIAO は **USB コネクタをシルク「USB」の側（基板の上辺、U1・D1 のある側。電池端子 J1 の反対側）** に向けて挿す。上辺側は USB-C ケーブルが届くよう空けてあります |
| H1〜H4 | M3 穴 | スペーサ／ネジ |

### B-3. はんだ付けの順番（背の低いもの → 高いもの）

1. 抵抗 R1, R2, R3, R4, R5, R7（足を曲げて挿し、裏ではんだ付け、余った足を切る）
2. ダイオード D1（帯の向きを確認してから）
3. セラミックコンデンサ C1, C2, C3, C5, C6
4. ピンヘッダ J3（使う場合）
5. XIAO 用ピンソケット A1 × 2（まっすぐ立つように、1 ピンだけ仮止めして角度を直してから残りをはんだ付け。**XIAO はまだ挿さない**）
6. Q2（TO-251）
7. U1、Q1、U2（TO-220 系）
8. C4（OS-CON、極性を再確認）
9. 端子台 J1、J2（差し込み口を基板の外側へ）

はんだ付け後、裏面をルーペで見て**隣のパッドとつながっていないか**、はんだの不足がないかを確認。

### B-4. 通電チェック（XIAO を挿す前に）

テスターの黒棒は GND（J1 の「−」、または J3 の GND ピン）に当てます。電池ボックス（L91 ×4）または安定化電源 6.0 V を J1 につなぎます（赤 → +、黒 → −）。

| # | 測るところ | 期待値 | 意味 |
|---|---|---|---|
| 1 | D1 の「K」側（U1 の VIN 側） | 電池電圧 −0.2〜0.4 V | 逆接保護ダイオードを通った VBAT |
| 2 | U1 の VOUT（= XIAO ソケットの 3V3 位置、J3 の 3V3 ピン） | **3.25〜3.35 V** | 3.3 V 常時レール |
| 3 | J2 の RED（5 V レール） | **0 V** | センサレールは平常時 OFF |
| 4 | ジャンパ線で **XIAO ソケットの D10 位置**（= R3 の XIAO 側）を 3.3 V（J3 の 3V3 ピン）に触れさせながら J2 の RED | **4.9〜5.1 V**（TSD20 版: 3.25〜3.35 V）。離すと 0 V | SENSOR_EN = High で Q2 → Q1 → U2 が ON |
| 5 | 同じく D10 を 3.3 V に触れさせながら Q1 の D（U2 の VIN）= VBAT_SW | 電池電圧（離すと 0 V） | 高側スイッチが ON |
| 6 | 同じく D10 を 3.3 V に触れさせながら **XIAO ソケットの A0 位置**（R1/R2 の中点） | **電池電圧のほぼ半分**。離すと **0 V** | 分圧は VBAT_SW から給電（スリープ中は 0 V） |

全部合格したら電源を外し、XIAO を挿します（向きは B-2 の A1 を参照）。

### B-5. XIAO を挿してから

- **基板のシルク「NO USB WHILE BATTERY CONNECTED!」の通り、電池をつないだまま USB を挿さない。** 書き込みは電池を外して USB だけで行う（手順は [03_firmware.md](03_firmware.md)）。
- 書き込み後、USB を外し、電池をつなぐ。ファームウェアの `rail on` / `tfmini raw 500` 相当の確認と、電池と直列の µA 電流計でのスリープ電流測定（目標 ≤ 90 µA、ブレッドボード実測 ≈ 26 µA）を行う。
- TFmini の 4 本線は J2 に **RED / BLK / GRN / WHT** の順（上から）で締める。締めたあと軽く引いて抜けないことを確認。

---

## C. 筐体・設置（検討中）

### C-1. 筐体（プレースホルダ）

筐体は**検討中**です。前のプロトタイプではタカチ **BCAP091208G**（内寸 66 × 96 mm）を使い、PCB v1.2 はその 50 mm 辺を幅方向にして収まる寸法にしてあります。防水・光学窓（TFmini のレンズ前）・電池ボックスの固定方法が決まり次第、ここに追記します。

### C-2. 照準のルール（設計仕様書 §5・§4.5 より）

1. 幹に取り付けて**鉛直下向きに測らない**。幹の直下は樹冠と幹からの放射で雪が少なく（tree well）、過小評価になる。
2. **θ = 20〜30° の斜め照準**で、幹から 2〜5 m 離れた開けた雪面を狙う（取付高 4 m・θ 25° なら幹から約 1.9 m 先、斜距離約 4.4 m）。
3. 照準先に下草・倒木・吹き溜まりがないことをチェックリストで確認し、設置時に照準先の写真を残す。
4. 傾き θ は毎回 IMU が測るので、取付角は厳密でなくてよい（取付後のずれの検出にも使う）。**基板は筐体内で鉛直に、USB コネクタ左・センサ端子 J2 上・電池端子 J1 右・D0〜D6（TX）ピン列下の向きで固定する**（2026-09-11 に 180° 変更。センサのケーブルは筐体内を上へ回して J2 に入れる）。この向きが θ = 0 の基準（[coordinate_system.md](coordinate_system.md)）。向きが上下逆だと `tilt` が 180° 付近になるので、設置時にアプリのライブ表示で確かめる。
5. 積雪深 = (無雪時の基準斜距離 d0 − 現在の斜距離 d) × cos θ。**設置時に必ず ZERO（無雪面なら基準距離取得）または「積雪深の実測値からの基準設定」をアプリで行う。**
6. **電源の入切を繰り返さない。** 本体は電池の接触不良などで何度も電源が入り直すと、ブラウンアウトのループと区別できないため、電池を守るために測定開始を遅らせます（1 回につき 10 分、最大 12 回で測定停止）。電池は**一度でしっかり入れる**。何度か入れ直してしまった場合でも、**設置作業でアプリを接続すれば解除されます**（人が現地にいる＝ループではない、と本体が判断します。`fw-2026-09-11` 以降）。
7. **最後に電源を入れてから最初の自動観測まで最大 10 分かかります。** すぐに記録が増えなくても故障ではありません。その場で動作を確かめたいときは、アプリのライブ表示か ZERO（基準設定）を使ってください。

アプリでの ZERO・時刻合わせ・データ回収の手順は [04_app.md](04_app.md) を参照。

## 通電チェックで値が合わないとき

| 症状 | 疑う場所 |
|---|---|
| 赤レールに電池電圧が出ない | J1 の極性、D1 の向き（帯 = カソードが基板側 = VBAT） |
| 3.3 V が出ない／低い | U1 の向き（印字面が下＝XIAO 側、VOUT-VIN-GND）、C1/C2 のはんだ、U1 の VIN に電圧が来ているか |
| SENSOR_EN を High にしても 5 V が出ない | Q2 の向き（G-D-S）、R3/R4 の値（R3 = R4 = 10 kΩ は NG）、Q1 の向きと R5 |
| 5 V が常に出ている（切れない） | **R3 の足が隣の列 22（3.3 V）に触れていないか**（実例あり: ⑩ の抜き差しでずれ、Q2 ゲートが常時 High → 118 mA 流れっぱなし）、Q1 の G-S 間短絡、R5 の有無、Q2 の D-S 短絡 |
| A0 が Vbat/2 にならない | R1/R2 の値が同じか、分圧の上端が VBAT_SW（Q1 のドレイン側）に付いているか |
| TFmini から応答がない | J2 の配線色（赤 5V・黒 GND・緑 TX→D7・白 RX←D6）、R7 の有無、レールが 5 V か |

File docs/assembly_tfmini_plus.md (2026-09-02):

# SnowGauge 組立説明書 — TFmini Plus 版(初号機)

- 版: v1.0(2026-09-02)
- 対象: 設計仕様書 v0.9 §4 のアーキテクチャに基づく TFmini Plus 構成(5V センサレール)
- 想定基板: ユニバーサル基板(スルーホール)。XIAO はピンソケット実装を推奨(交換可能にするため)
- **初心者向けビジュアル版**: [assembly_guide_visual.html](assembly_guide_visual.html)(部品写真+配線図付き。本書はエンジニア向けリファレンス)

---

## 1. 配線の全体像

```
BAT+ ──▶|── VBAT ──┬─────────────────────────┬──────────────┐
     1N5819        │                         │              │
    (逆接保護)      │ [常時系]                 │ [測定時のみ系]  │ [電圧監視]
                   │                         │              │
                   ▼                         ▼              ▼
             NJU7223F33               2SJ334 (P-ch)       R1 1MΩ
             VIN  VOUT ── 3V3_SYS     S ── D = VBAT_SW      │
              │    │        │         G ─┬─ R5 100kΩ ─ VBAT ├── ADC_NODE ── XIAO A0(D0)
             GND  0.1µF   XIAO 3V3    │  │                  │
                   +10µF              │  ▼                 R2 1MΩ
                                      │ NJU7223F50          │
                          Q2 2SK4017  │ VIN VOUT ─ 5V_SENS  ▼
                          D ──────────┘  │    │        Q3 2SK4017
                          G ─ R3 10kΩ ─ XIAO D2(SENSOR_EN)  D
                          │  R4 100kΩ ─ GND    │            G ── XIAO D3(VBAT_MEAS_EN)
                          S ─ GND              │            │    R6 100kΩ ─ GND
                                     C3 0.1µF + C4 470µF    S ─ GND
                                     (OS-CON)  │
                                               ▼
                                          TFmini Plus 赤(+5V)

UART:  XIAO D6(TX) ── R7 1kΩ ── TFmini 白(RX)
       XIAO D7(RX) ─────────── TFmini 緑(TX)
       TFmini 黒(GND) ── GND(共通)
```

## 2. 部品表(この基板で使う分)

| 記号 | 部品 | 型番 | 備考 |
|---|---|---|---|
| D1 | ショットキー | 1N5819 | 帯(カソード)が VBAT 側 |
| U1 | 3.3V LDO(常時) | NJU7223F33 | TO-220F。正面から 1=VOUT, 2=VIN, 3=GND |
| U2 | 5V LDO(遮断側) | NJU7223F50 | 同上ピン配置。TSD20 機では F33 に差し替え |
| Q1 | 高側スイッチ P-ch | 2SJ334 | 1=G, 2=D(タブ), 3=S |
| Q2, Q3 | 低側スイッチ N-ch | 2SK4017 ×2 | 1=G, 2=D, 3=S |
| R1, R2 | 1MΩ 1/4W | 分圧 | ±0.1V 精度で可(カーボン) |
| R3 | 10kΩ | Q2 ゲート直列 | |
| R4, R6 | 100kΩ | Q2/Q3 ゲートプルダウン | スリープ・リセット中の誤ONを防止 |
| R5 | 100kΩ | Q1 G-S プルアップ(→VBAT) | スリープ中のセンサレール確実OFF |
| R7 | 1kΩ | TX 直列 | 幽霊給電・短絡時の保護 |
| C1, C2, C3, C5 | 0.1µF X7R | U1/U2 の入出力直近 | 各 LDO の VIN・VOUT 両方に必須 |
| C4 | OS-CON 470µF/16V | 5V_SENS レール | 極性注意。TFmini ピーク 500mA 吸収 |
| C6 | 10µF | 3V3_SYS レール | XIAO 近傍 |
| A1 | XIAO nRF52840 Sense | — | ピンソケット実装推奨 |
| — | 電池ボックス 単3×4 | — | L91×4 |
| — | TFmini Plus | — | 付属ケーブル: 赤=+5V, 黒=GND, 緑=TX, 白=RX(**現物のデータシートで要確認**) |

## 3. ネットリスト(配線チェック用)

| ネット | 接続先(すべて列挙) |
|---|---|
| BAT+ | 電池+ → D1 アノード |
| VBAT | D1 カソード / U1-VIN / C1 / Q1-S / R5 上端 / R1 上端 |
| 3V3_SYS | U1-VOUT / C2 / C6 / XIAO 3V3 ピン |
| SENSOR_EN | XIAO D2 → R3 → Q2-G(R4 で GND へ) |
| Q1_GATE | Q1-G / R5 下端 / Q2-D |
| VBAT_SW | Q1-D / U2-VIN / C3 |
| 5V_SENS | U2-VOUT / C5 / C4+ / TFmini 赤 |
| ADC_NODE | R1 下端 / R2 上端 / XIAO A0(D0) |
| VBAT_MEAS_EN | XIAO D3 / Q3-G(R6 で GND へ) |
| MEAS_GND_SW | R2 下端 / Q3-D |
| UART_TX | XIAO D6 → R7 → TFmini 白(RX) |
| UART_RX | XIAO D7 ← TFmini 緑(TX) |
| GND | 電池− / U1-GND / U2-GND / Q2-S / Q3-S / R4 / R6 / 各コンデンサ− / XIAO GND / TFmini 黒 |

## 4. XIAO ピンアサイン(FW と共有する正)

| XIAO ピン | 信号 | 方向 | 役割 |
|---|---|---|---|
| 3V3 | 3V3_SYS | 電源入力 | 外部 LDO から給電(オンボードレギュレータは不使用) |
| GND | GND | — | 共通グラウンド |
| D0 / A0 | ADC_NODE | AIN | 電池電圧 = 読み値 ×2(分圧 1/2) |
| D2 | SENSOR_EN | OUT | High でセンサレール ON |
| D3 | VBAT_MEAS_EN | OUT | High で分圧通電(測定時のみ) |
| D6 | UART_TX | OUT | → TFmini RX(遮断前に Hi-Z/Low 化) |
| D7 | UART_RX | IN | ← TFmini TX |

D1, D4, D5, D8–D10 は空き(D4/D5 は将来の外付け I2C センサ用に温存。基板にパッドを残すこと)。

## 5. 組立手順

**順序の原則: 電源部を先に完成させて単体検証 → その後に XIAO・LiDAR を接続。** 逆接・過電圧事故から高価な部品を守ります。

### Step 1: 電源部(常時系)

1. 背の低い部品から実装: R 類 → D1 → C1/C2/C6 → U1
2. 0.1µF は **LDO のピンの直近**(数 mm 以内)に配置
3. 電池ボックスを接続し、テスターで確認:
   - [ ] VBAT ≈ 電池電圧 − 0.2〜0.35V(ショットキー降下)
   - [ ] 3V3_SYS = 3.25〜3.35V

### Step 2: 高側スイッチ+5V 系

1. Q1, Q2, R3, R4, R5 → U2, C3, C5 → C4(**極性注意**: OS-CON の長脚が+)
2. 検証(XIAO なしで手動テスト):
   - [ ] 無操作時(SENSOR_EN 開放): 5V_SENS = 0V(R4 のプルダウンで OFF が正常)
   - [ ] SENSOR_EN 相当の Q2 ゲートをジャンパ線で 3V3_SYS に接続: 5V_SENS = 4.9〜5.1V
   - [ ] ジャンパを外す: 5V_SENS が 0V に戻る

### Step 3: 電圧監視部

1. R1, R2, R6, Q3 を実装
2. 検証:
   - [ ] Q3 ゲート開放時: ADC_NODE ≈ VBAT(電流は流れないため分圧されず浮く。異常ではない)
   - [ ] Q3 ゲートを 3V3_SYS に接続: ADC_NODE = VBAT ÷ 2

### Step 4: XIAO 実装

1. ピンソケットを半田付けし、XIAO を装着
2. **重要: USB を接続するときは必ず電池を外す**(3V3 ピンへの外部給電と USB 給電の衝突を避ける)
3. 電池のみで XIAO の LED が起動することを確認(出荷時 FW で可)

### Step 5: TFmini Plus 接続

1. 付属コネクタ(JST GH 系)経由で接続。ケーブル色は現物で要確認
2. UART 線(R7 経由の TX、RX)を接続
3. FW のテストスケッチ(開発側で用意)で:
   - [ ] SENSOR_EN ON → TFmini 通電 → 距離フレーム受信
   - [ ] SENSOR_EN OFF → 5V_SENS = 0V、TFmini 消費 0

### Step 6: 最終確認(スリープ電流)

- [ ] µA レンジの電流計を電池と直列に入れ、スリープ時 **90µA 以下**(目標 ~50µA)を確認
- 超過時の容疑者: QSPI フラッシュの deep power-down 漏れ / IMU パワーダウン漏れ / TX の Hi-Z 化漏れ(幽霊給電)/ Q2・Q3 の誤 ON

## 6. 注意事項まとめ

- **USB と電池の同時接続禁止**(Step 4 参照)
- OS-CON・LDO の**極性/ピン配置を実装前に現物のデータシートで再確認**(TO-220 の 1-2-3 は品種で異なる)
- TFmini Plus の UART は 3.3V LVTTL(データシート明記)なので直結可。R7 1kΩ は幽霊給電対策の保険
- 半田ごては TO-220F(フルモールド)の放熱タブに無理な熱をかけない
- 屋外投入前に、筐体内で数日間の連続動作試験(レコード蓄積+スリープ電流)を行う

---

**【重要・2026-09-02追記】PCB版(pcb/)では SENSOR_EN が D2 → D10 に変更されました。**FWおよびPCBでの正は [pcb/README.md](../pcb/README.md) のピンマップです。本書§4のピンアサインは手配線(ブレッドボード)時のもの。

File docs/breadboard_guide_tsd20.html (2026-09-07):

SnowGauge — breadboard prototype / TSD20

# SnowGauge ブレッドボード配線図

PCB が届くまでの開発・ファームウェア検証用に、はんだ付けなしで SnowGauge（TSD20 版、U2 = NJU7223F33）を組む配線図です。TFmini Plus 版は breadboard_guide.html（違いは U2 とセンサ配線だけ、§5 参照）。830 穴ブレッドボード 1 枚とジャンパワイヤで組めます。回路は PCB v1.2 と同一トポロジ（電池監視の分圧をスイッチ済みレールに接続。Q3・R6 は廃止）なので、ここで書いたファームウェアはそのまま PCB で動きます。

## 1座標の読み方

列番号（1〜63）×行（a〜e / f〜j）で穴を指定します。同じ列の a〜e、f〜j はそれぞれ内部でつながっています（中央の溝をまたぐと別グループ）。上下の赤・青の長いレールは横一列すべてつながっています。

- 上の赤レール = VBAT（ダイオード通過後の電池+）／ 上の青レール = GND
- 下の赤・青レールは使いません（すべて上のレールに戻します）
- 例: c10 = 10 列目の c 行。部品の両端は図中の●の脇に穴名を書いてあります。レールへ行く線は同じ列のレール穴に挿してあれば十分です（レール上の位置は自由）

## 2全体配線図

丸数字は下のチェックリストの番号。各部品・線の両端に穴名を表示しています（ステップごとの拡大図は §3）。

VBATGND3.3VVBAT_SW(スイッチ後)センサ 3.3V ノード(測定時のみ)Q1ゲート電圧測定TSD20 赤 = 3.3VTSD20 黄 = TX→XIAO D7TSD20 緑 = RX←XIAO D6TSD20 黒 = GND

## 3組立チェックリスト

上から順に。各ステップ末尾のテスター確認に合格してから次へ。XIAO と TSD20 を挿すのは電源確認のあとです。図はそのステップの部品を色付き、前のステップまでを薄く表示しています。

### STEP 1電源部

番号 | 部品/線 | 端 A（穴） | 端 B（穴） | 備考
① | 電池ボックス 赤線(+) | c2 | （外部）
② | D1 1N5819 | b2 | b6 | 帯(カソード)を b6 側に
③ | ジャンパ 赤 | a6 | 上の赤レール(VBAT)
④ | U1 NJU7223F33 | c10=OUT / c11=IN / c12=GND | | 印字面を手前にして左から OUT / IN / GND
⑤ | ジャンパ 赤 | a11 | 上の赤レール(VBAT)
⑥ | 電池ボックス 黒線(−) | 上の青レール(GND) | （外部）
⑦ | ジャンパ 黒 | a12 | 上の青レール(GND)
⑧ | C1 0.1µF | e11 | e12
⑧ | C2 0.1µF | d10 | d12
⑧ | C6 10µF | b10 | b12 | 向きなし

- 赤レール−青レール間: 電池電圧 −0.2〜0.35V
- c10（U1 の OUT）−青レール間: 3.25〜3.35V

### STEP 2XIAO

番号 | 部品/線 | 端 A（穴） | 端 B（穴） | 備考
⑨ | XIAO nRF52840 Sense | e20〜e26: 5V GND 3V3 D10 D9 D8 D7/RX | f20〜f26: D0/A0 D1 D2 D3 D4 D5 D6/TX | 列 20〜26 に溝をまたいで挿す。USB コネクタが左（列 20 側）。部品面を上にして見ると上列が 5V…D7、下列が D0…D6
⑩ | ジャンパ 橙 (3.3V) | a10 | a22 | U1 の OUT 列 → XIAO 3V3 ピン(e22)の列
⑪ | ジャンパ 黒 | a21 | 上の青レール(GND) | XIAO GND ピン(e21)の列 → 上の青レール

- XIAO の 3V3 ピン(e22)−GND ピン(e21) 間 = 3.3V（SnowGauge FW は LED を使わないので LED は点きません）

最重要: パソコンと USB でつなぐ時は必ず電池を抜く。USB を挿したまま電池（や安定化電源）でセンサ側を動かしたい時は、⑩（橙、a10→a22）だけ抜けば両立できます（XIAO は USB 給電、センサレールと分圧は電池給電。GND は共通のまま）。向きを間違えて挿すと壊れるので、⑨は挿す前に指差し確認。

### STEP 3スイッチと センサ 3.3V 系

番号 | 部品/線 | 端 A（穴） | 端 B（穴） | 備考
⑫ | Q2 2SK4017 | c28=G / c29=D / c30=S | | 印字面を手前にして左から G / D / S
⑬ | R3 10kΩ | b23 | b28 | XIAO D10 ピン(e23)の列 ↔ Q2 の G 列
⑭ | R4 100kΩ | a28 | 上の青レール(GND) | Q2 の G 列 → 上の青レール（プルダウン）
⑮ | ジャンパ 黒 | a30 | 上の青レール(GND) | Q2 の S 列 → 上の青レール
⑯ | Q1 2SJ334 | c32=G / c33=D / c34=S | | 印字面を手前にして左から G / D / S
⑰ | R5 100kΩ | b32 | b34 | Q1 の G–S 間（プルアップ）
⑱ | ジャンパ (Q1ゲート) | a29 | a32 | Q2 の D 列 → Q1 の G 列
⑲ | ジャンパ 赤 | a34 | 上の赤レール(VBAT) | Q1 の S 列 → 上の赤レール
⑳ | U2 NJU7223F33 | c38=OUT / c39=IN / c40=GND | | TFmini 版はここが F50。印字で確認
㉑ | ジャンパ (VBAT_SW) | a33 | a39 | Q1 の D 列 → U2 の IN 列
㉒ | ジャンパ 黒 | a40 | 上の青レール(GND) | U2 の GND 列 → 上の青レール
㉓ | C3 0.1µF | e39 | e40
㉔ | C4 OS-CON 470µF | b42 | b44 | 極性注意: 長い足(+) を b42、− を b44
㉔ | C5 0.1µF | c42 | c44
㉕ | ジャンパ (センサ 3.3V) | a38 | a42 | U2 の OUT 列 → センサ 3.3V ノード
㉖ | ジャンパ 黒 | a44 | 上の青レール(GND) | C4 の − 列 → 上の青レール

- なにもしない時: e42−GND 間 = 0V
- ジャンパ線で a28（Q2 の G）を 3.3V（c10）に触れさせる: e42 = 3.25〜3.35V、離すと 0V に戻る（4.9〜5.1V なら U2 が F50 のまま。TSD20 をつなぐ前に必ず直す）
- a28 を c10 に触れさせている間: a32（Q1 の G）= 0V 近く、a33（Q1 の D = VBAT_SW）= 電池電圧。離している時は逆に a32 ≈ 電池電圧、a33 = 0V

### STEP 4電池電圧の見張り（スイッチ済みレールから分圧）

番号 | 部品/線 | 端 A（穴） | 端 B（穴） | 備考
㉗ | R1 1MΩ | e33 | e36 | Q1 の D 列(VBAT_SW) ↔ 36 列
㉘ | R2 1MΩ | b36 | b41
㉙ | ジャンパ 黒 | a41 | 上の青レール(GND)
㉚ | ジャンパ 紫 (電圧測定) | a36 | g20 | 分圧の中点 → XIAO A0(D0) ピン(f20)の列（溝をまたぐ）

- STEP 3 と同じく a28 を c10 に触れさせている間: a36−GND 間 = 電池電圧のほぼ半分。離している時は 0V

FW メモ: 電池電圧はセンサレール ON 中に A0 を読む（読み値 ×2）。旧設計の D3・Q3・R6 は廃止。

### STEP 5TSD20

番号 | 部品/線 | 端 A（穴） | 端 B（穴） | 備考
㉛ | R7 1kΩ | g26 | g31 | XIAO D6(TX) ピン(f26)の列 ↔ 31 列
㉜ | TSD20 ④ 緑 (RX) | h31 | （外部） | R7 の先（XIAO D6 TX → 1kΩ → TSD20 RX）。TFmini の白と同じ穴
㉝ | TSD20 ③ 黄 (TX) | a26 | （外部） | XIAO D7(RX) ピン(e26)の列。TFmini の緑と同じ穴
㉞ | TSD20 ② 赤 (+3.3V) | e42 | （外部） | センサ 3.3V ノード（U2=F33 の出力。5V ではない！）
㉟ | TSD20 ⑥ 黒 (GND) | 上の青レール(GND) | （外部） | ①白 と ⑤水色 は NC（未接続のまま）

- TSD20 版 FW（overlay-tsd20.conf ビルド、BLE 名 SG-TSD-XXXX）で: rail on → lidar raw 500（tsd20 raw も可）で dist=xxxx mm のフレーム受信（460800 baud、200Hz）、lidar read で cksum_err=0、rail off → e42 = 0V
- µA 電流計を電池と直列に: スリープ 90µA 以下（ブレッドボードは接触・リークで数 µA 上振れすることあり）

TSD20 のリード線（6 本、20cm、先端すずめっき）は基板上のコネクタ側で左から 白・赤・黄・緑・水色・黒 = ピン 1=NC, 2=3.3V, 3=TX, 4=RX, 5=NC, 6=GND（色は手持ち品の実物で確認、説明書に記載なし。赤=3.3V・黒=GND が並びの根拠）。TFmini との対応: 赤→赤、緑→黄、白→緑、黒→黒。線は末端加工なしの極細線なので、そのままでは挿せません。被覆をむいた単線ジャンパ（またはピンヘッダの足）に 1 本ずつはんだ付けし、継ぎ目を熱収縮チューブで覆ってから挿します（動作確認だけならミノムシクリップでも可。ねじって巻くだけは電源線では不可）。継ぎ目の手前で線をテープで固定して引っ張りを逃がすこと。安定化電源の電流制限は 0.5A 以上（TSD20 ピーク 70mA + XIAO）。TSD20 には逆接・過電圧保護がないので、②を 5V ノードや VBAT に挿さないこと。

## 4注意メモ

- 電池を入れたまま USB をつながない（STEP 2 参照。例外は⑩を抜いた時のみ）
- 向きがある部品: D1（帯）、C4（長い足が+）、U1/U2/Q1/Q2（1-2-3 の並び、印字面を手前に）。F33 と F50 は印字で読み分け
- TSD20 のピーク電流は 70mA なので配線の接触抵抗には寛容。U2 の出力（e42 ノード）が 3.3V であることを、TSD20 をつなぐ前に必ず確認する（F50 が残っていると 5V がかかって壊れる）
- スリープ電流の最終評価は PCB で行う（ブレッドボードはリークが乗るため参考値）
- 抵抗の代替値（手持ちで組む場合）: R3 は 150Ω〜2.2kΩ（R4 との分圧で Q2 のゲート電圧が 2.7V 以上になること。R3=R4=10k は NG）、R4・R5 は 10kΩ 可、R1/R2 は 同じ値なら 5k〜1M のどれでも（FW は「読み値 ×2」）、R7 は 1k〜5k。分圧は VBAT_SW 側なのでスリープ電流には影響しない

## 5TFmini Plus 版 ⇄ TSD20 版の組み替え

同じ基板・同じ配線で、変わるのは U2（センサ用 LDO）とセンサの 4 本の線だけ。ファームウェアも別ビルド（TFmini 版 = 既定、TSD20 版 = overlay-tsd20.conf、BLE 名は SG-TFM- / SG-TSD-）。

1. 電源を切る（電池・安定化電源・USB すべて外す）。センサの線を 4 本とも抜く
2. U2 を差し替える: c38–c40 の NJU7223F50 を抜き、同じ向き（印字面を手前に OUT–IN–GND）で NJU7223F33 を挿す（逆方向は F33 → F50）。C3/C4/C5 と㉑〜㉖のジャンパはそのまま
3. 電源を入れ、STEP 3 の確認: a28 を c10 に触れさせて e42 = 3.25〜3.35V（TSD20 版） / 4.9〜5.1V（TFmini 版）。この確認を飛ばして TSD20 に 5V をかけると壊れます（逆接・過電圧保護なし）
4. センサをつなぐ（電源を切ってから）。TSD20 は線の色ではなくピン番号で: ② 赤 3.3V → e42、③ 黄 TX → a26（XIAO D7 RX の列）、④ 緑 RX → h31（R7 の先）、⑥ 黒 GND → 青レール。① 白・⑤ 水色 は NC。TFmini は 赤 → e42、緑 → a26、白 → h31、黒 → 青レール
5. 該当バリアントの FW を書き込み、STEP 5 の確認（rail on → lidar raw 500）。TSD20 版はフレームが dist=xxxx mm（460800 baud）で出る

USB と電池/安定化電源を同時につなぐ時のルール（⑩を抜く）はどちらの版も同じ。

SnowGauge 設計仕様書 v0.13 / PCB v1.2 トポロジ準拠（分圧は VBAT_SW から・Q3/R6/D3 廃止）。ピン配置の正は pcb/README.md。この HTML（TSD20 版）は docs/gen_breadboard.py --tsd20 が生成します（手編集しない）。

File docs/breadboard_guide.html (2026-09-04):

SnowGauge — breadboard prototype / TFmini Plus

# SnowGauge ブレッドボード配線図

PCB が届くまでの開発・ファームウェア検証用に、はんだ付けなしで SnowGauge を組む配線図です。830 穴ブレッドボード 1 枚とジャンパワイヤで組めます。回路は PCB v1.2 と同一トポロジ（電池監視の分圧をスイッチ済みレールに接続。Q3・R6 は廃止）なので、ここで書いたファームウェアはそのまま PCB で動きます。

## 1座標の読み方

列番号（1〜63）×行（a〜e / f〜j）で穴を指定します。同じ列の a〜e、f〜j はそれぞれ内部でつながっています（中央の溝をまたぐと別グループ）。上下の赤・青の長いレールは横一列すべてつながっています。

- 上の赤レール = VBAT（ダイオード通過後の電池+）／ 上の青レール = GND
- 下の赤・青レールは使いません（すべて上のレールに戻します）
- 例: c10 = 10 列目の c 行。部品の両端は図中の●の脇に穴名を書いてあります。レールへ行く線は同じ列のレール穴に挿してあれば十分です（レール上の位置は自由）

## 2全体配線図

丸数字は下のチェックリストの番号。各部品・線の両端に穴名を表示しています（ステップごとの拡大図は §3）。

VBATGND3.3VVBAT_SW(スイッチ後)5V(測定時のみ)Q1ゲート電圧測定UART TX→白UART 緑→RX

## 3組立チェックリスト

上から順に。各ステップ末尾のテスター確認に合格してから次へ。XIAO と TFmini を挿すのは電源確認のあとです。図はそのステップの部品を色付き、前のステップまでを薄く表示しています。

### STEP 1電源部

番号 | 部品/線 | 端 A（穴） | 端 B（穴） | 備考
① | 電池ボックス 赤線(+) | c2 | （外部）
② | D1 1N5819 | b2 | b6 | 帯(カソード)を b6 側に
③ | ジャンパ 赤 | a6 | 上の赤レール(VBAT)
④ | U1 NJU7223F33 | c10=OUT / c11=IN / c12=GND | | 印字面を手前にして左から OUT / IN / GND
⑤ | ジャンパ 赤 | a11 | 上の赤レール(VBAT)
⑥ | 電池ボックス 黒線(−) | 上の青レール(GND) | （外部）
⑦ | ジャンパ 黒 | a12 | 上の青レール(GND)
⑧ | C1 0.1µF | e11 | e12
⑧ | C2 0.1µF | d10 | d12
⑧ | C6 10µF | b10 | b12 | 向きなし

- 赤レール−青レール間: 電池電圧 −0.2〜0.35V
- c10（U1 の OUT）−青レール間: 3.25〜3.35V

### STEP 2XIAO

番号 | 部品/線 | 端 A（穴） | 端 B（穴） | 備考
⑨ | XIAO nRF52840 Sense | e20〜e26: 5V GND 3V3 D10 D9 D8 D7/RX | f20〜f26: D0/A0 D1 D2 D3 D4 D5 D6/TX | 列 20〜26 に溝をまたいで挿す。USB コネクタが左（列 20 側）。部品面を上にして見ると上列が 5V…D7、下列が D0…D6
⑩ | ジャンパ 橙 (3.3V) | a10 | a22 | U1 の OUT 列 → XIAO 3V3 ピン(e22)の列
⑪ | ジャンパ 黒 | a21 | 上の青レール(GND) | XIAO GND ピン(e21)の列 → 上の青レール

- XIAO の 3V3 ピン(e22)−GND ピン(e21) 間 = 3.3V（SnowGauge FW は LED を使わないので LED は点きません）

最重要: パソコンと USB でつなぐ時は必ず電池を抜く。USB を挿したまま電池（や安定化電源）でセンサ側を動かしたい時は、⑩（橙、a10→a22）だけ抜けば両立できます（XIAO は USB 給電、センサレールと分圧は電池給電。GND は共通のまま）。向きを間違えて挿すと壊れるので、⑨は挿す前に指差し確認。

### STEP 3スイッチと 5V 系

番号 | 部品/線 | 端 A（穴） | 端 B（穴） | 備考
⑫ | Q2 2SK4017 | c28=G / c29=D / c30=S | | 印字面を手前にして左から G / D / S
⑬ | R3 10kΩ | b23 | b28 | XIAO D10 ピン(e23)の列 ↔ Q2 の G 列
⑭ | R4 100kΩ | a28 | 上の青レール(GND) | Q2 の G 列 → 上の青レール（プルダウン）
⑮ | ジャンパ 黒 | a30 | 上の青レール(GND) | Q2 の S 列 → 上の青レール
⑯ | Q1 2SJ334 | c32=G / c33=D / c34=S | | 印字面を手前にして左から G / D / S
⑰ | R5 100kΩ | b32 | b34 | Q1 の G–S 間（プルアップ）
⑱ | ジャンパ (Q1ゲート) | a29 | a32 | Q2 の D 列 → Q1 の G 列
⑲ | ジャンパ 赤 | a34 | 上の赤レール(VBAT) | Q1 の S 列 → 上の赤レール
⑳ | U2 NJU7223F50 | c38=OUT / c39=IN / c40=GND | | TSD20 版はここを F33 に
㉑ | ジャンパ (VBAT_SW) | a33 | a39 | Q1 の D 列 → U2 の IN 列
㉒ | ジャンパ 黒 | a40 | 上の青レール(GND) | U2 の GND 列 → 上の青レール
㉓ | C3 0.1µF | e39 | e40
㉔ | C4 OS-CON 470µF | b42 | b44 | 極性注意: 長い足(+) を b42、− を b44
㉔ | C5 0.1µF | c42 | c44
㉕ | ジャンパ (5V) | a38 | a42 | U2 の OUT 列 → 5V ノード
㉖ | ジャンパ 黒 | a44 | 上の青レール(GND) | C4 の − 列 → 上の青レール

- なにもしない時: e42−GND 間 = 0V
- ジャンパ線で a28（Q2 の G）を 3.3V（c10）に触れさせる: e42 = 4.9〜5.1V、離すと 0V に戻る
- a28 を c10 に触れさせている間: a32（Q1 の G）= 0V 近く、a33（Q1 の D = VBAT_SW）= 電池電圧。離している時は逆に a32 ≈ 電池電圧、a33 = 0V

### STEP 4電池電圧の見張り（スイッチ済みレールから分圧）

番号 | 部品/線 | 端 A（穴） | 端 B（穴） | 備考
㉗ | R1 1MΩ | e33 | e36 | Q1 の D 列(VBAT_SW) ↔ 36 列
㉘ | R2 1MΩ | b36 | b41
㉙ | ジャンパ 黒 | a41 | 上の青レール(GND)
㉚ | ジャンパ 紫 (電圧測定) | a36 | g20 | 分圧の中点 → XIAO A0(D0) ピン(f20)の列（溝をまたぐ）

- STEP 3 と同じく a28 を c10 に触れさせている間: a36−GND 間 = 電池電圧のほぼ半分。離している時は 0V

FW メモ: 電池電圧はセンサレール ON 中に A0 を読む（読み値 ×2）。旧設計の D3・Q3・R6 は廃止。

### STEP 5TFmini Plus

番号 | 部品/線 | 端 A（穴） | 端 B（穴） | 備考
㉛ | R7 1kΩ | g26 | g31 | XIAO D6(TX) ピン(f26)の列 ↔ 31 列
㉜ | TFmini 白 (RX) | h31 | （外部） | R7 の先
㉝ | TFmini 緑 (TX) | a26 | （外部） | XIAO D7(RX) ピン(e26)の列
㉞ | TFmini 赤 (+5V) | e42 | （外部） | 5V ノード
㉟ | TFmini 黒 (GND) | 上の青レール(GND) | （外部）

- テスト FW で: rail on → tfmini raw 500 で距離フレーム受信、rail off → e42 = 0V
- µA 電流計を電池と直列に: スリープ 90µA 以下（ブレッドボードは接触・リークで数 µA 上振れすることあり）

TFmini の線が細くて抜けやすい場合は、ピンヘッダ付きジャンパをかませるか、線先にピンを圧着してください。安定化電源で代用する場合は電流制限を 1A 以上 に（TFmini 起動時ピーク 500mA）。

## 4注意メモ

- 電池を入れたまま USB をつながない（STEP 2 参照。例外は⑩を抜いた時のみ）
- 向きがある部品: D1（帯）、C4（長い足が+）、U1/U2/Q1/Q2（1-2-3 の並び、印字面を手前に）。F33 と F50 は印字で読み分け
- TFmini のピーク電流(500mA)はブレッドボードの接触抵抗に厳しいので、電源系のジャンパは短く太いものを。測距が不安定なら C4 の追加や配線短縮を試す
- スリープ電流の最終評価は PCB で行う（ブレッドボードはリークが乗るため参考値）
- 抵抗の代替値（手持ちで組む場合）: R3 は 150Ω〜2.2kΩ（R4 との分圧で Q2 のゲート電圧が 2.7V 以上になること。R3=R4=10k は NG）、R4・R5 は 10kΩ 可、R1/R2 は 同じ値なら 5k〜1M のどれでも（FW は「読み値 ×2」）、R7 は 1k〜5k。分圧は VBAT_SW 側なのでスリープ電流には影響しない

SnowGauge 設計仕様書 v0.12 / PCB v1.2 トポロジ準拠（分圧は VBAT_SW から・Q3/R6/D3 廃止）。ピン配置の正は pcb/README.md。TSD20 版は U2 を NJU7223F33 に差し替えるだけで同一配線。この HTML は docs/gen_breadboard.py が生成します（手編集しない）。

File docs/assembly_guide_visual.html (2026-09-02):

SnowGauge — TFmini Plus variant / rev.1

# SnowGauge 組立ガイド

積雪深ロガー SnowGauge(TFmini Plus 版)をユニバーサル基板で組み立てるための手順書です。電子工作がはじめてでも、部品の向きと配線番号のとおりに進めれば完成するように書いてあります。テスター(電圧測定)だけは使えるようにしておいてください。

## 1まず全体像

この装置は「ふだんは眠っていて、1日8回だけ起きてレーザーで雪面までの距離を測る」機械です。電気の流れは3系統に分かれます。

眠っている間の消費をとことん減らすため、レーザー距離計は使う瞬間だけ通電します。そのスイッチ役がトランジスタ(2SJ334・2SK4017)です。

## 2部品図鑑 — 向きの見分け方

左が実物の写真、右がピン配置図です。足に番号がある部品は、向きを間違えると壊れます。はんだ付けの前に毎回この図と見比べてください。

XIAO nRF52840 Sense

XIAO nRF52840 Senseマイコン

頭脳。時計・Bluetooth・傾きセンサ内蔵。オレンジ色の丸が今回使うピン。

向き: USBコネクタを上にして、左列の上から D0…、右列の上から 5V, GND, 3V3, D7(=RX), D6(=TX)。5Vピンは使いません。

TFmini Plus

TFmini Plusレーザー距離計

目。赤外レーザーで雪面までの距離を測ります(防水 IP65)。

向き: コネクタは逆挿しできない形ですが、線の色(赤=電源, 黒=GND, 緑=TX, 白=RX)を付属の説明書で必ず確認。

NJU7223F33

NJU7223F333.3V 変換 ×2個

電池の約6Vを 3.3V に落とす部品(レギュレータ)。1個は常時系、もう1個は TSD20 版で使う予備。

向き: 印字面を手前にして左から 1=出力, 2=入力, 3=GND。F50(5V版)と外見がそっくり——印字「F33/F50」を必ず読む。

NJU7223F50

NJU7223F505V 変換

TFmini Plus 用に 5V を作るレギュレータ。トランジスタのスイッチの後ろに置くので、測定時しか電気を食いません。

向き: F33 と同じ(1=出力, 2=入力, 3=GND)。

2SJ334

2SJ334Q1 メインスイッチ

5V 系の元栓。マイコンの合図で電池からの電気を入り切りします(Pチャネル MOSFET)。

向き: 印字面を手前にして左から 1=G(合図), 2=D(出口), 3=S(入口=電池側)。

2SK4017

2SK4017 ×2Q2, Q3 小スイッチ

Q2 はメインスイッチ Q1 を操作する係、Q3 は電池電圧の見張り回路を入り切りする係(N チャネル MOSFET)。

向き: 印字面を手前にして左から 1=G, 2=D, 3=S。静電気に弱いので足を触りすぎない。

1N5819

1N5819D1 逆接保護

電池を逆向きに入れてしまった時に回路を守る一方通行弁(ダイオード)。

向き: 帯(カソード)が回路側、帯なし側が電池+側。逆に付けると全く動きません。

OS-CON 470uF

OS-CON 470µF/16VC4 バルクコンデンサ

TFmini が瞬間的に大電流を吸う時の「貯水タンク」。低温に強い特別品。

向き: 極性あり! 長い足が+(5V側)、側面の帯がある側が−(GND側)。逆に付けると壊れます。

0.1uF セラミックコンデンサ

0.1µF セラミック ×6C1,C2,C3,C5 ほか

電圧のさざ波を消す小さなコンデンサ。レギュレータの足元(数mm以内)に付けるのがコツ。

向き: なし(どちら向きでも OK)。印字は「104」。

抵抗

抵抗(カーボン 1/4W)R1〜R7

電流を制限したり、スイッチの誤動作を防いだりする部品。値ごとに色の帯が違います。

向き: なし。1MΩ=茶黒緑金 / 100kΩ=茶黒黄金 / 10kΩ=茶黒橙金 / 1kΩ=茶赤赤金。自信がなければテスターで測って仕分け。

## 3配線図 — 線は全部で30本

上の赤い線が「VBATレール」(電池+の共通線)、下の黒い線が「GNDレール」(電池−の共通線)。ユニバーサル基板ではこの2本をすずメッキ線などで通しておき、各部品からそこへつなぎます。丸数字は §4 のチェックリストの番号と対応しています。

電池+ (VBAT) GND 3.3V 5V(測定時のみ) センサON合図 Q1ゲート 見張りON合図 電圧測定 UART 送信→白 UART 緑→受信

※ 線が交差している所はつながっていません。つながる所には黒丸(●)を描いてあります。C1・C2・C3・C5(0.1µF)と C6(10µF)は図を簡単にするため省略——各レギュレータの IN-GND 間と OUT-GND 間、XIAO の 3V3-GND 間に、それぞれ足元最短で付けます(チェックリスト⑥⑦⑯参照)。

## 4組立チェックリスト — この順番で

番号は配線図の丸数字と同じです。1本つなぐごとにチェックし、各ステップ最後の「テスター確認」に合格してから次へ進んでください。順番どおりに作ると、高い部品(XIAO・TFmini)を接続する前に電源の安全を確認できます。

### STEP 1電源部(常時ON系)をつくる

番号 | 線の種類 | どこから → どこへ
① | 電池+ | 電池ボックスの赤線 → D1 の帯なし側
② | 電池+ | D1 の帯あり側 → VBATレール
③ | GND | 電池ボックスの黒線 → GNDレール
④ | 電池+ | VBATレール → U1(F33)の2番:IN
⑤ | GND | U1 の3番:GND → GNDレール
⑥ | 部品 | C1(0.1µF)を U1 の 2番-3番の間、足元最短で
⑦ | 部品 | C2(0.1µF)+C6(10µF)を U1 の 1番-GND の間に

### テスター確認(電池を入れて)

- VBATレール − GNDレール間: 約 5.7〜6.1V(電池電圧よりダイオードの分 0.2〜0.35V 低い)
- U1 の 1番(OUT) − GND間: 3.25〜3.35V
- ここで電圧が出ない/おかしい場合は D1 の向きと U1 の印字(F33 か)を確認

### STEP 2スイッチと 5V 系をつくる

番号 | 線の種類 | どこから → どこへ
⑧ | 電池+ | VBATレール → Q1(2SJ334)の3番:S
⑨ | 部品 | R5(100kΩ)を Q1 の1番:G と VBATレールの間に(眠っている間スイッチを確実にOFFにする係)
⑩ | ゲート | Q2(2SK4017)の2番:D → Q1 の1番:G
⑪ | GND | Q2 の3番:S → GNDレール
⑫ | 合図 | XIAO の D2(あとで挿すソケット位置)→ R3(10kΩ)→ Q2 の1番:G
⑬ | 部品 | R4(100kΩ)を Q2 の 1番:G と GNDレールの間に
⑭ | 電池+ | Q1 の2番:D → U2(F50)の2番:IN
⑮ | GND | U2 の3番:GND → GNDレール
⑯ | 部品 | C3(0.1µF)を U2 の 2番-3番間、C5(0.1µF)を 1番-GND間に
⑰ | 5V | U2 の1番:OUT → 5Vライン(TFmini へ向かう線)
⑱ | 部品 | C4(OS-CON 470µF)を 5Vライン(+)と GNDレール(−)の間に。長い足が5V側!

### テスター確認(XIAO はまだ挿さない)

- なにもしない状態: 5Vライン − GND間 = 0V(スイッチOFFが正常)
- ジャンパ線で「R3 の XIAO側」を U1 の 3.3V出力に触れさせる: 5Vライン = 4.9〜5.1V
- ジャンパ線を離す: 0V に戻る

### STEP 3電池の見張り回路をつくる

番号 | 線の種類 | どこから → どこへ
⑲ | 測定 | VBATレール → R1(1MΩ)→ 中間点(=ADCノード)
⑳ | 測定 | 中間点 → R2(1MΩ)→ Q3(2SK4017)の2番:D
㉑ | GND | Q3 の3番:S → GNDレール
㉒ | 合図 | XIAO の D3(ソケット位置)→ Q3 の1番:G
㉓ | 部品 | R6(100kΩ)を Q3 の 1番:G と GNDレールの間に
㉔ | 測定 | 中間点 → XIAO の A0(ソケット位置)

### テスター確認

- ジャンパ線で Q3 の G を 3.3V に触れさせると、中間点 = VBATのちょうど半分(約3V)
- ジャンパ線を離すと中間点はほぼ VBAT まで浮く(電流が流れていない証拠。故障ではない)

### STEP 4XIAO を挿す

番号 | 線の種類 | どこから → どこへ
㉕ | 3.3V | U1 の1番:OUT → XIAO の 3V3ピン(ソケット位置)
㉖ | GND | XIAO の GNDピン → GNDレール

- 先にピンソケット(メス)だけを基板にはんだ付けし、配線が全部終わってから XIAO 本体を挿します
- 挿す向きは「部品図鑑」の図のとおり(USBコネクタの位置で確認)

最重要: パソコンと USB でつなぐときは、必ず電池を抜くこと。電池と USB の電気がぶつかって XIAO が壊れることがあります。「電池を入れたまま USB を挿さない」と基板にマジックで書いておくくらいでちょうどいいです。

### 確認

- 電池だけで XIAO の LED が点く(工場出荷ファームで確認可)

### STEP 5TFmini Plus をつなぐ

番号 | 線の種類 | どこから → どこへ
㉗ | 5V | 5Vライン → TFmini の赤線
㉘ | GND | TFmini の黒線 → GNDレール
㉙ | UART | XIAO の D6(TX) → R7(1kΩ)→ TFmini の白線(RX)
㉚ | UART | TFmini の緑線(TX) → XIAO の D7(RX)

### 確認(テスト用ファームウェアを書き込んで)

- 測定コマンドで TFmini が起動し、距離の数字が返ってくる
- スリープ中は 5Vライン = 0V
- 電流計(µAレンジ)を電池と直列に入れて、スリープ電流 90µA以下(目標 約50µA)

## 5こわさないための約束ごと

- 電池を入れたまま USB をつながない(STEP 4 参照)
- 向きのある部品は4つ: D1(帯の向き)・C4(長い足が+)・トランジスタ3個(1-2-3の並び)・レギュレータ2個(F33/F50の読み分け)。はんだ付け前に部品図鑑と照合
- はんだ付けは「背の低い部品から」: 抵抗 → ダイオード → コンデンサ(小) → トランジスタ/レギュレータ → ソケット → 電解コンデンサ
- トランジスタ・XIAO は静電気に弱いので、作業前に金属(水道の蛇口など)に触れて体の静電気を逃がす
- 各ステップのテスター確認を飛ばさない——あとから原因を探すほうが何倍も大変
- 屋外に持ち出す前に、部屋で数日間動かしっぱなしにして記録とスリープ電流を確認する

SnowGauge 設計仕様書 v0.9 に基づく(TFmini Plus 版)。部品写真: 秋月電子通商・スイッチサイエンスの各商品ページより(社内組立用資料)。回路の詳細・ネットリストはリポジトリの docs/assembly_tfmini_plus.md を参照。

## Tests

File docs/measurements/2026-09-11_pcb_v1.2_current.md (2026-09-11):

# PCB v1.2 current: sleep, BLE and a full logging cycle — 2026-09-11

First power measurement on the **assembled PCB v1.2** (everything before this was the
breadboard). One uninterrupted hour with the logger measuring every 5 minutes.

Setup: PCB v1.2, TFmini Plus on the switched rail, **four used Energizer L91 cells**
(6.31 V at rest, no bench supply), **picowatt** (INA228, 15 mΩ) in the supply line,
`--mode single --adcrange 1 --preset quiet` (118.8 Sa/s) with `--cal`, so the stored zero
offset (−81.0 µA, range 1) is applied per sample and no difference method is needed.
Firmware: TFmini build of `295adc8` + the −Y tilt axis (`SNOWGAUGE_SENSOR_AXIS_NEG_Y`),
schedule all day / 5 min, clock synced, no phone connected except where noted.

## Results

| Item | Value | Note |
|---|---|---|
| **Sleep + BLE advertising** | **31.7 µA** (sem 0.2, 423k samples) | adv 1–2 s, WDT running |
| Phone connected (BLE link up) | **+100…150 µA** | for as long as the app stays connected |
| **Measurement cycle** | **37.23 µAh** (37.21–37.40 over 11 cycles), **1.57 s** | IMU → rail on → 100 frames → rail off |
| Burst peak / plateau | 328 mA / 114 mA | peak = inrush into the 470 µF OS-CON |
| Pack voltage under load | 6.31 V → **5.34 V** | used cells, recovers immediately |
| Duty cycle at 5 min | 0.48 % | |
| **Mean current, 5 min interval** | **441 µA** (441.5 µAh in 60 min) | bench schedule, not the field one |
| **Extrapolated, field schedule** | **45.7 µA** = 1.096 mAh/day | 9 measurements/day (17:00–05:00 / 90 min) |
| Battery life at that rate | **≈7.5 years** on 3000 mAh | cell chemistry, self-discharge and cold not included |

The breadboard numbers it replaces: sleep 32 µA ± 10 and 0.037 mAh per cycle
(`2026-09-03_breadboard_current.md`, `2026-09-07_wdt_breadboard_current.md`). **The PCB
draws the same**; 37.23 µAh vs 0.037 mAh per cycle is the same number measured more
precisely. The spread across 11 cycles is 0.5 %.

Data: `data/2026-09-11_pcb_5min_1h_1Hz.csv` (the hour, 1 Hz: mean/max current and minimum
vbus per second) and `data/2026-09-11_pcb_burst_119Hz.csv` (one cycle at full rate).
Summary produced by `tools/analyze_power.py`.

## Two things the hour taught us

**1. The reset backoff delayed the first measurement by more than half an hour.** The first
attempt at this measurement recorded no cycles at all for 26 minutes. Cause: the
consecutive-reset counter (NVS `sgd/boots`) had been driven up by power-cycling the board
while wiring the meter, and the scheduler holds the first measurement off by
`CONFIG_SNOWGAUGE_BOOT_HOLDOFF_MIN` (10 min) × that count, halting measurements entirely at
12. After one clean power cycle the first cycle came exactly 10 minutes later and every 5
minutes after that — 11 cycles in the hour, all on schedule. This is a design problem for
installation, not a bench artefact, and the firmware was changed the same day: a BLE
connection now drops the backoff (someone is standing at the logger, so the resets were
human), and the counter is cleared by a measurement that actually ran the sensor rail
instead of by a 10-minute timer, which is what makes the protection work at all.

**2. Keep the phone connection short.** An open BLE link costs more than three times the
sleep current. Connecting for a 5-minute site visit is nothing (≈12 µAh), but an app left
connected for an hour costs as much as three measurement cycles.

## Method note

`--cal` makes single captures usable on their own: the 09-07 measurements needed a zero run
with the DUT lead pulled, and the zero drift between runs was the dominant error (±10 µA).
Here the stored calibration is applied per sample, and with 423k sleep samples the
statistical error is 0.2 µA. The remaining uncertainty is the calibration itself, not the
capture.

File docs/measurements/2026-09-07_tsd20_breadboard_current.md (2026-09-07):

# Breadboard current measurements, TSD20 variant — 2026-09-07

Setup: same breadboard as `2026-09-03_breadboard_current.md` with **U2 = NJU7223F33 and a
PONO TSD20** on the switched 3.3 V rail (`docs/breadboard_guide_tsd20.html`), XIAO fed
through jumper ⑩, USB disconnected. Supply: bench PSU 6.00 V, **picowatt** (INA228, 15 mΩ,
ADCRANGE=1) in the supply line. Firmware: TSD20 build of commit `81eed78`
(`overlay-tsd20.conf`, N = 100 frames at 200 Hz, rail settle 300 ms, BLE advertising 1–2 s).
The scheduled measurement was provoked by setting the schedule to all day / 30 min from the
app and capturing across 13:00 (`--preset normal`, 908 Sa/s).

## Measurement burst (IMU + rail + 100 TSD20 frames), one scheduled cycle

| Item | Value | Note |
|---|---|---|
| Duration (rail on → rail off) | **0.95 s** | TFmini: 1.58 s |
| Inrush at rail switch-on | 650–670 mA for ~2 ms | C4 (470 µF) charging; 2 samples |
| Sensor boot phase | ≈ 11 mA for ~150 ms | rail on until the TSD20 starts streaming |
| Streaming plateau | **41.7 mA** (max 44.7) for ~0.75 s | manual: average 40 mA, peak 70 mA |
| Charge per cycle | **35.3 mA·s = 0.0098 mAh** | TFmini: 0.037 mAh → **≈ ¼** |
| 8 cycles/day | 0.078 mAh/day ≈ **0.9 µA average** | TFmini: 3.5 µA |

Profile (50 ms bins, baseline subtracted): rail on at t = 0 → 11 mA until +0.15 s →
42 mA from +0.15 s (sensor streaming; the firmware only starts reading at +0.30 s) →
off at +0.90 s. The rail settle time could be shortened to ~200 ms (saves ~4 mA·s, 10 %) — **decided against on 2026-09-07 (user): the gain is ≈0.1 µA average and the 300 ms margin covers the LDO/OS-CON start-up and sensor boot across temperature; keep 300 ms.**
Data: `data/2026-09-07_tsd20_burst_900Hz.csv` (burst window only).

BLE advertising spikes seen in the same capture: every ~1 s, mean 4.6 mA above baseline
per sample, max 31 mA, as before.

## Sleep current (whole system, TSD20 build, advertising on)

Difference method as in the 09-03 notes (`--preset very-quiet`, 7.6 Sa/s).

| Item | Value | Note |
|---|---|---|
| Raw, DUT connected (60 s) | −37.7 µA (sd 43) | 12:47, sd = advertising bursts |
| Zero, DUT lead c2 pulled (40 s) | −73.6 µA (sd 25) | 13:06; zero drift vs. 09-04 (−70 µA) ≈ 3 µA |
| Raw, DUT reinserted (60 s) | −40.1 µA (sd 41) | 13:09; drift check: 2.4 µA from the first run (a reset + boot hold-off in between) |
| **Sleep + advertising, whole system, TSD20** | **36 µA ± 10** | TFmini board with the same firmware generation: 32 µA ± 10 (09-04) → no measurable difference |

Sensor-side change vs. the TFmini board is only U2 (F33 instead of F50, same family) and
the sensor itself (no power when the rail is off), so no difference is expected.

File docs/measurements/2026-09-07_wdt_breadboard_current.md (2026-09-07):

# Breadboard sleep current with the watchdog build — 2026-09-07

Setup: TFmini breadboard as in `2026-09-03_breadboard_current.md` (U2 = NJU7223F50, TFmini
Plus on the switched rail), XIAO fed through jumper ⑩, USB disconnected. Supply: bench PSU
6.00 V, **picowatt** (INA228, 15 mΩ, ADCRANGE=1, `--preset very-quiet`, 7.6 Sa/s) in the
supply line. Firmware: TFmini build of commit `a5ec340` (hardware WDT 120 s, supervisor work
every 30 s, BLE advertising 1–2 s, payload v2). Captured during the boot hold-off, so no
measurement cycle is included.

## Sleep + advertising, whole system (difference method)

| Item | Value | Note |
|---|---|---|
| Raw, DUT connected (60 s) | −45.4 µA (sd 57) | 15:0x, sd = advertising bursts |
| Zero, DUT lead c2 pulled (40 s) | −66.9 µA (sd 34) | zero drifted ≈ +7 µA vs. 09-07 morning (−73.6) |
| Raw, DUT reinserted (60 s) | −44.9 µA (sd 42) | |
| **Sleep + advertising + WDT supervisor** | **22 µA ± 10** | 09-04 release build on the same board: 32 µA ± 10 |

The watchdog itself runs from the LFCLK that BLE keeps on anyway, and the supervisor wakes
the CPU for a few tens of µs every 30 s, so no increase was expected; the ~10 µA "drop" is
within the method's uncertainty (zero drift between runs is the dominant error). Conclusion:
enabling the WDT costs nothing measurable.

Data: `data/2026-09-07_wdt_sleep_{raw1,zero,raw2}.csv`.

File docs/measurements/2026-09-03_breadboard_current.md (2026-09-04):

# Breadboard current measurements — 2026-09-03

Setup: breadboard (docs/breadboard_guide.html, resistor substitutes R3=150Ω, R4=R5=10k,
R1=R2=5k, R7=2.2k), XIAO nRF52840 Sense fed through jumper ⑩ (3V3 pin), TFmini Plus on
the switched 5 V rail. Supply: bench PSU 6.00 V in place of the L91×4 pack, measured with
**picowatt** (INA228, 15 mΩ shunt, ADCRANGE=1, `very-quiet` preset = 4120 µs × 16 avg,
~7.6 Sa/s). Firmware: step 3 prep build (`3e31596` + VBUS-gated USB), auto measurement
every 60 s, N=100 TFmini frames.

## Method notes (picowatt at µA level)

- 1 µV across 15 mΩ = 67 µA, so terminal thermo-EMF / contact potentials matter. The
  INA228 zero moved by tens of µA whenever wiring was touched. Reliable procedure:
  **difference measurement** — pull only the DUT lead (breadboard c2) without touching the
  picowatt terminals, record the zero (40 s), reinsert, record (60 s), subtract.
- Per-sample noise ≈ 18–20 µA (sd) at `very-quiet`; 60 s averages have ~1 µA standard
  error; zero drift over minutes ≈ ±10 µA → quote results as ±10 µA.
- A broken supply(−)–Pico GND link shows up as a 50 Hz half-wave on VBUS (mean ≈ 18 V for
  a 6 V supply) and 250 µA-class current noise. Check `--preset normal` VBUS sd first.

## Results

| Item | Value | Note |
|---|---|---|
| Sleep current, whole system, **USB enabled at boot (board default)** | **1.89 mA** | udc_nrf keeps HFXO + USBD on regardless of VBUS |
| Sleep current, whole system, **USB gated by VBUS** (`usb_pm.c`) | **17 µA ± 10** | raw −53.3 µA vs zero −70.0 µA; 10 s blocks within ±3 µA |
| Sensor side only (XIAO on USB, ⑩ pulled) | ≈ 45 µA (uncertain zero) | U1 quiescent + D1 leakage; superseded by the whole-system figure |
| Measurement burst (IMU + 100 TFmini frames) | 1.58 s, peak 115–117 mA, **133–138 mA·s = 0.037 mAh** | 8/day → 0.30 mAh/day ≈ 3.5 µA average |
| TFmini alone (accidentally on VBAT rail) | 117.9 mA continuous | wiring error found this way |

Budget check (spec §7.1 assumed 50 µA typ / 90 µA worst sleep + 15–35 µA measurements):
measured ≈ 17 + 3.5 ≈ **21 µA** before BLE advertising. BLE adv (1–2 s interval) is
expected to add ~10–20 µA. Final numbers to be re-measured on PCB v1.2.

## Re-measurement with FW step 4a (record storage), 2026-09-03 afternoon

Firmware `1dccdfa` (LittleFS mounted on the QSPI, QSPI under runtime PM / deep
power-down, rtc-emul 1 Hz work item, mirror partition), shell-only build (no auto
measurement), PSU 6.00 V, USB disconnected, ⑩ in. Same difference method.

| Item | Value | Note |
|---|---|---|
| Raw, DUT connected (60 s) | −53.9 µA (sd 18) | |
| Zero, DUT lead c2 pulled (40 s) | −71.7 µA (sd 24) | |
| Raw, DUT reinserted (60 s) | −53.6 µA (sd 18) | drift check: within 0.3 µA of the first run |
| **Sleep current, whole system, step 4a** | **18 µA ± 10** | unchanged vs. step 3 (17 µA) → LittleFS/runtime-PM QSPI and the 1 Hz rtc-emul tick cost nothing measurable |

## FW step 4b: BLE status advertising, 2026-09-03 afternoon

Firmware `ea2bde3`: connectable advertising, interval 1000–2000 ms (SoftDevice
Controller picks within the window), 31-byte ADV + scan response with the name.
PSU 6.00 V, USB disconnected, ⑩ in, shell-only build.

| Item | Value | Note |
|---|---|---|
| Raw, DUT connected (60 s) | −44.9 µA (sd 42) | 10 s blocks −42…−48 µA; larger sd = advertising bursts |
| Zero, DUT lead c2 pulled (40 s) | −70.5 µA (sd 21) | zero drift vs. the 4a run: 1.2 µA |
| **Sleep + advertising, whole system** | **26 µA ± 10** | |
| **BLE advertising increment (1–2 s)** | **≈ +8 µA** | vs. 18 µA without BLE |

Running total ≈ 26 µA + 3.5 µA measurements ≈ **30 µA average**, against the spec
§7.1 budget of 50 µA typ / 90 µA worst. The advertising interval stays a knob
(`ble adv <ms>`; 2 s fixed would roughly halve the +8 µA).

## Release firmware fw-2026-09-04 (step 4d + robustness pass), 2026-09-04 afternoon

Same setup and difference method. Board on PSU only, ⑩ in, clock synced, schedule
17:00–05:00 / 90 min (no slot during the capture), advertising 1–2 s, live off.

| Item | Value | Note |
|---|---|---|
| Raw, ⑩ out (XIAO unpowered, sensor side only, 60 s) | −52.9 µA (sd 18) | U1 quiescent + D1/Q1 leakage ≈ **20 µA** vs. the zero below |
| Raw, ⑩ in (whole system, 60 s) | −41.2 µA (sd 37) | 10 s blocks −39…−45 µA; sd = advertising bursts |
| Zero, DUT lead c2 pulled (40 s) | −72.9 µA (sd 22) | |
| **Sleep + advertising, whole system, release FW** | **32 µA ± 10** | 26 µA on the step-4b build; same within the method's ±10 µA. Settings/NVS, cal work queue, rtc-emul tick: no measurable cost |
| XIAO + BLE share (derived) | ≈ 12 µA | whole system − sensor side |

Bench incident the same afternoon: 118 mA continuous with the MCU reporting the rail
OFF. Cause: R3's lead (row b, columns 23–28) had shifted and touched column 22 (3.3 V),
holding Q2's gate high → Q1 on. Reseating R3 fixed it (Q2 was swapped meanwhile; the
original was probably fine). Added to docs/02_assembly.md troubleshooting.

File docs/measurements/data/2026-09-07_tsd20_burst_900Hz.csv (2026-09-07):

t_s | ch | vbus_V | current_A | power_W
3551.135859 | 0 | 6.001758 | 0.0001660 | 0.0009963
3551.136975 | 0 | 6.000586 | 0.0000620 | 0.0003720
3551.138032 | 0 | 5.995508 | -0.0002080 | -0.0012471
3551.139090 | 0 | 5.998438 | -0.0001660 | -0.0009957
3551.140206 | 0 | 5.995508 | -0.0000200 | -0.0001199
3551.141263 | 0 | 5.997461 | 0.0000200 | 0.0001199
3551.142321 | 0 | 5.997266 | -0.0001860 | -0.0011155
3551.143436 | 0 | 6.002734 | -0.0004780 | -0.0028693
3551.144494 | 0 | 5.996484 | -0.0002280 | -0.0013672
3551.145610 | 0 | 5.997656 | -0.0000620 | -0.0003719
3551.146668 | 0 | 5.997070 | -0.0002080 | -0.0012474
3551.147725 | 0 | 6.001367 | 0.0001240 | 0.0007442
3551.148841 | 0 | 6.000977 | -0.0001860 | -0.0011162
3551.149899 | 0 | 6.000586 | 0.0000400 | 0.0002400
3551.151014 | 0 | 5.999414 | 0.0000400 | 0.0002400
3551.152072 | 0 | 5.999414 | -0.0000200 | -0.0001200
3551.153130 | 0 | 5.998242 | 0.0001660 | 0.0009957
3551.154247 | 0 | 5.999219 | 0.0000620 | 0.0003720
3551.155305 | 0 | 5.997852 | 0.0004780 | 0.0028670
3551.156363 | 0 | 5.998633 | -0.0000200 | -0.0001200
3551.157478 | 0 | 5.996875 | -0.0003540 | -0.0021229
3551.158536 | 0 | 5.996289 | 0.0000200 | 0.0001199
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

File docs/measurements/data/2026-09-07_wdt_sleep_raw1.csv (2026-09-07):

t_s | ch | vbus_V | current_A | power_W
3429.664866 | 0 | 5.998828 | -0.0000500 | -0.0002999
3429.796654 | 0 | 5.998633 | -0.0000620 | -0.0003719
3429.928489 | 0 | 5.998828 | -0.0000600 | -0.0003599
3430.060333 | 0 | 5.999023 | -0.0000400 | -0.0002400
3430.192170 | 0 | 5.998633 | -0.0000340 | -0.0002040
3430.324329 | 0 | 5.998828 | -0.0000260 | -0.0001560
3430.455808 | 0 | 5.999023 | 0.0000300 | 0.0001800
3430.587643 | 0 | 5.999023 | -0.0000740 | -0.0004439
3430.719495 | 0 | 5.998633 | -0.0000340 | -0.0002040
3430.851276 | 0 | 5.999023 | -0.0000640 | -0.0003839
3430.983154 | 0 | 5.998828 | -0.0000380 | -0.0002280
3431.114991 | 0 | 5.998633 | -0.0000660 | -0.0003959
3431.246770 | 0 | 5.998828 | -0.0000340 | -0.0002040
3431.378606 | 0 | 5.998828 | -0.0000480 | -0.0002879
3431.510426 | 0 | 5.998828 | 0.0001220 | 0.0007319
3431.642290 | 0 | 5.998828 | -0.0000360 | -0.0002160
3431.774125 | 0 | 5.998828 | -0.0000740 | -0.0004439
3431.905924 | 0 | 5.999023 | -0.0000960 | -0.0005759
3432.037768 | 0 | 5.999219 | -0.0000640 | -0.0003840
3432.169572 | 0 | 5.999219 | -0.0000560 | -0.0003360
3432.301407 | 0 | 5.998828 | -0.0000300 | -0.0001800
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

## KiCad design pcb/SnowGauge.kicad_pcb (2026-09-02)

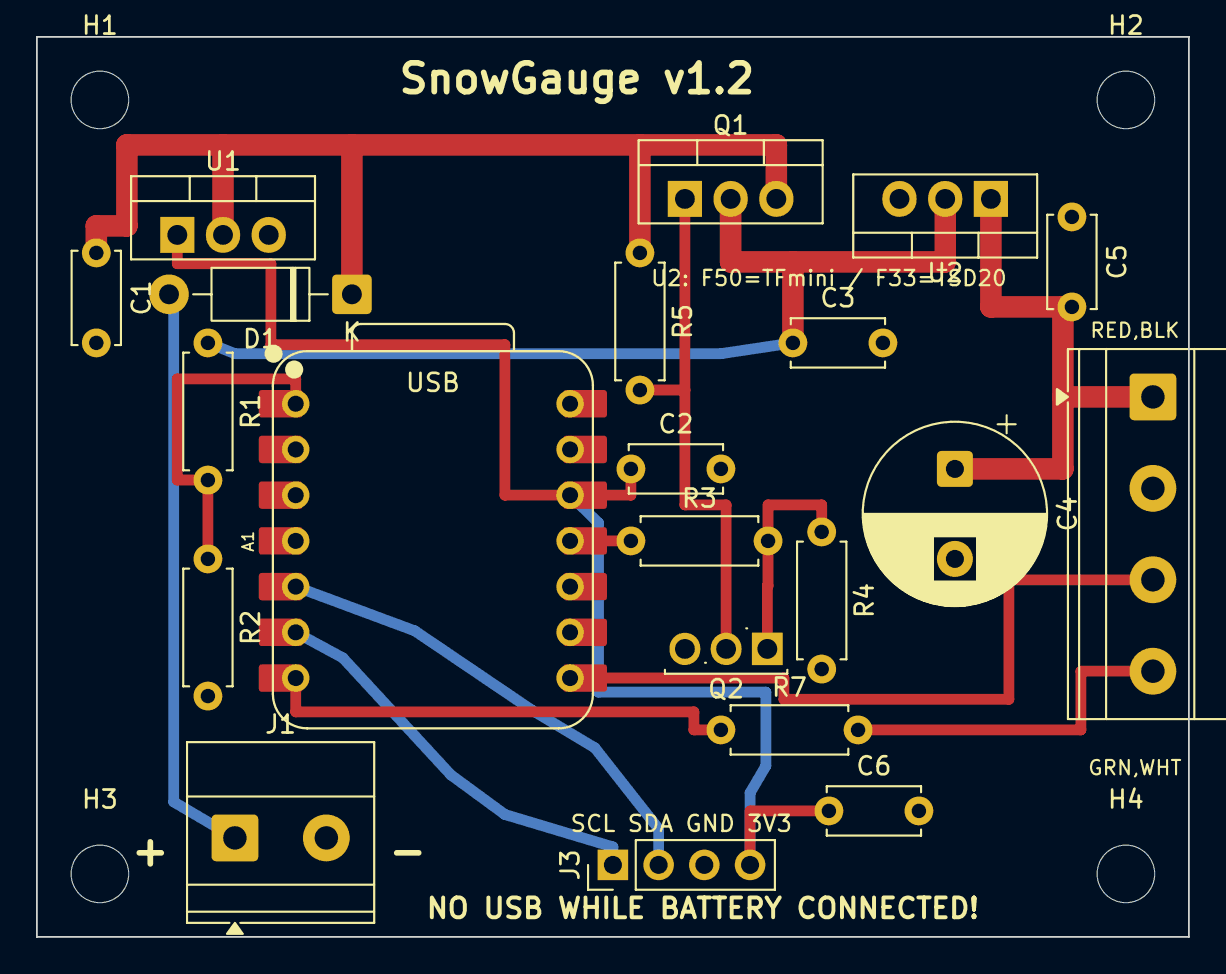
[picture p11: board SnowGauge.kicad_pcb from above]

Board: 2 copper layers, 64.0 x 50.0 mm, 25 parts (0 on the bottom side), 15 nets.

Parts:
A1: XIAO nRF52840 Sense; XIAO-nRF52840-DIP
C1, C2, C3, C5: 0.1u; C_Disc_D5.0mm_W2.5mm_P5.00mm
C4: OS-CON 470u/16V; CP_Radial_D10.0mm_P5.00mm
C6: 10u; C_Disc_D5.0mm_W2.5mm_P5.00mm
D1: 1N5819; D_DO-41_SOD81_P10.16mm_Horizontal
H1, H2, H3, H4: M3; MountingHole_3.2mm_M3
J1: BATTERY L91x4; TerminalBlock_Phoenix_MKDS-1,5-2-5.08_1x02_P5.08mm_Horizont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
J2: TFmini 2Px2; TerminalBlock_Phoenix_MKDS-1,5-4-5.08_1x04_P5.08mm_Horizont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
J3: I2C SPARE; PinHeader_1x04_P2.54mm_Vertical
Q1: 2SJ334; TO-220-3_Vertical
Q2: 2SK4017; TO-251-3_Vertical
R1, R2: 1M; R_Axial_DIN0207_L6.3mm_D2.5mm_P7.62mm_Horizontal
R3: 10k; R_Axial_DIN0207_L6.3mm_D2.5mm_P7.62mm_Horizontal
R4, R5: 100k; R_Axial_DIN0207_L6.3mm_D2.5mm_P7.62mm_Horizontal
R7: 1k; R_Axial_DIN0207_L6.3mm_D2.5mm_P7.62mm_Horizontal
U1: NJU7223F33; TO-220-3_Vertical
U2: NJU7223F50; TO-220-3_Vertical

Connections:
3V3_SYS: A1.12, C2.1, C6.1, J3.4, U1.1
5V_SENS: C4.1, C5.2, J2.1, U2.1
ADC_NODE: A1.1, R1.2, R2.1
BATP_RAW: D1.2, J1.1
GND: A1.13, C1.2, C2.2, C3.2, C4.2, C5.1, C6.2, J1.2, J2.2, J3.3, Q2.3, R2.2, R4.2, U1.3, U2.3
I2C_SCL: A1.6, J3.1
I2C_SDA: A1.5, J3.2
Q1_GATE: Q1.1, Q2.2, R5.2
Q2_G: Q2.1, R3.2, R4.1
SENSOR_EN: A1.11, R3.1
TFMINI_RX: J2.4, R7.2
UART_RX: A1.8, J2.3
UART_TX_MCU: A1.7, R7.1
VBAT: C1.1, D1.1, Q1.3, R5.1, U1.2
VBAT_SW: C3.1, Q1.2, R1.1, U2.2

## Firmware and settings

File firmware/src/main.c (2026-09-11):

/*
 * SnowGauge firmware.
 *
 * Boots with the sensor rail off and the sensor UART parked (Hi-Z), opens a
 * shell on USB CDC ACM, and optionally runs a measurement cycle every
 * CONFIG_SNOWGAUGE_AUTO_MEASURE_PERIOD_S seconds.
 */

#include <zephyr/kernel.h>
#include <nrfx.h>
#include <zephyr/logging/log.h>
#include <zephyr/sys/printk.h>
#include <stdarg.h>
#include <stdio.h>
#include <stdbool.h>

#include "app.h"
#include "sensor_rail.h"
#include "lidar.h"
#include "battery.h"
#include "measure.h"
#include "tilt.h"
#include "power.h"
#include "usb_pm.h"
#include "record.h"
#include "storage.h"
#include "timekeeping.h"
#include "ble_adv.h"
#include "config.h"
#include "cal_gatt.h"
#include "diag.h"
#include "wdt_mon.h"

LOG_MODULE_REGISTER(main, CONFIG_LOG_DEFAULT_LEVEL);

static K_SEM_DEFINE(period_changed, 0, 1);
static uint32_t auto_period_s = CONFIG_SNOWGAUGE_AUTO_MEASURE_PERIOD_S;

static void config_changed(void)
{
	k_sem_give(&period_changed);
}

void app_wake_scheduler(void)
{
	k_sem_give(&period_changed);
}

void app_set_auto_period(uint32_t seconds)
{
	auto_period_s = seconds;
	k_sem_give(&period_changed);
}

uint32_t app_get_auto_period(void)
{
	return auto_period_s;
}

static bool first_record_after_boot = true;

int app_measure_and_store(bool manual, struct measurement *m_out, struct record *r_out)
{
	struct measurement m;
	struct record r;
	uint32_t epoch = 0;
	int ret;

	wdt_mon_alive(WDT_CH_MEASURE, WDT_MEASURE_TIMEOUT_S);
	ret = measure_once(&m);
	if (m_out) {
		*m_out = m;
	}
	if (ret) {
		LOG_ERR("measurement failed (%d) - not stored", ret);
		(void)ble_adv_update(true);
		wdt_mon_disarm(WDT_CH_MEASURE);
		return ret;
	}

	record_from_measurement(&r, &m);
	if (time_now(&epoch) == 0) {
		r.epoch = epoch;
		r.flags |= (time_get_state() == TIME_SYNCED) ? RECORD_FLAG_TIME_SYNCED
							     : RECORD_FLAG_TIME_ESTIMATED;
	}
	if (manual) {
		r.flags |= RECORD_FLAG_MANUAL;
	}
	if (first_record_after_boot) {
		r.flags |= RECORD_FLAG_FIRST_AFTER_BOOT;
		first_record_after_boot = false;
	}
	r.seq = storage_next_seq();

	ret = storage_append(&r);
	if (ret) {
		LOG_ERR("record %u not stored (%d)", r.seq, ret);
	} else if (m.lidar_ret != -ENOTSUP) {
		/*
		 * Surviving the full-load rail burst and storing its record is the
		 * proof, regardless of distance validity; a low-battery skip is not.
		 */
		diag_measure_succeeded();
	}
	if (r_out) {
		*r_out = r;
	}
	(void)ble_adv_update(ret != 0);
	wdt_mon_disarm(WDT_CH_MEASURE);
	return ret;
}

static void printk_out(void *ctx, const char *fmt, ...)
{
	ARG_UNUSED(ctx);
	va_list ap;
	char line[160];

	va_start(ap, fmt);
	vsnprintf(line, sizeof(line), fmt, ap);
	va_end(ap);
	LOG_INF("%s", line);
}

int main(void)
{
	int ret;

	LOG_INF("SnowGauge FW (step 5: %s variant) - board " CONFIG_BOARD_TARGET, lidar_name());
	diag_init();

	ret = sensor_rail_init();
	if (ret) {
		LOG_ERR("sensor_rail_init: %d", ret);
	}
	ret = lidar_init();
	if (ret) {
		LOG_ERR("lidar_init: %d", ret);
	}
	ret = battery_init();
	if (ret) {
		LOG_ERR("battery_init: %d", ret);
	}
	ret = tilt_init();
	if (ret) {
		LOG_ERR("tilt_init: %d", ret);
	}
	ret = power_init();
	if (ret) {
		LOG_ERR("power_init: %d", ret);
	}
	ret = time_init();
	if (ret) {
		LOG_ERR("time_init: %d", ret);
	}
	ret = storage_init();
	if (ret) {
		LOG_ERR("storage_init: %d", ret);
	}
	ret = config_init();
	if (ret) {
		LOG_ERR("config_init: %d", ret);
	}
	(void)diag_count_boot(); /* needs the settings subsystem (config_init) */
	(void)time_restore_saved();
	(void)diag_log_boot();
	config_set_change_cb(config_changed);
	ret = ble_adv_init();
	if (ret) {
		LOG_ERR("ble_adv_init: %d", ret);
	}
	ret = cal_gatt_init();
	if (ret) {
		LOG_ERR("cal_gatt_init: %d", ret);
	}
	ret = usb_pm_init();
	if (ret) {
		LOG_ERR("usb_pm_init: %d", ret);
	}
	ret = wdt_mon_init();
	if (ret) {
		LOG_ERR("wdt_mon_init: %d", ret);
	}

	LOG_INF("ready - type 'help' in the USB shell (rail is OFF)");

	bool first = true;

	for (;;) {
		uint32_t period = auto_period_s;

		wdt_mon_alive(WDT_CH_MAIN, WDT_MAIN_TIMEOUT_S);
		if (diag_measure_halted()) {
			/* Reset loop: stay reachable over BLE, do not measure. */
			k_sem_take(&period_changed, K_MINUTES(10));
			first = true;
			continue;
		}
		if (period != 0) {
			/* Bench mode: fixed period from the shell / Kconfig. */
			if (!first && k_sem_take(&period_changed, K_SECONDS(period)) == 0) {
				first = true;
				continue;
			}
			first = false;
		} else {
			/* Field mode: schedule window from the settings, needs the clock. */
			uint32_t now, next;
			struct app_config c;

			config_get(&c);
			if (c.sched_interval_min == 0) {
				k_sem_take(&period_changed, K_MINUTES(10));
				first = true;
				continue;
			}
			/* Hold-off after a reset (see diag_init). */
			int64_t left_ms = (int64_t)diag_holdoff_until_s() * 1000 - k_uptime_get();

			if (left_ms > 0) {
				if (k_sem_take(&period_changed, K_MSEC(MIN(left_ms, 3600000))) == 0) {
					first = true;
				}
				continue;
			}
			if (time_now(&now) != 0) {
				/*
				 * Clock never set (sync forgotten at installation): still
				 * measure every interval from boot so nothing is lost; the
				 * records land in rec_notime.bin, ordered by seq.
				 */
				if (!first && k_sem_take(&period_changed, K_MINUTES(c.sched_interval_min)) == 0) {
					first = true;
					continue;
				}
				first = false;
				LOG_WRN("clock unset - measuring on the interval from boot");
			} else if ((next = config_next_measurement(now)) == 0) {
				k_sem_take(&period_changed, K_MINUTES(10));
				first = true;
				continue;
			} else if (next > now) {
				uint32_t wait_s = MIN(next - now, 3600U);

				if (k_sem_take(&period_changed, K_SECONDS(wait_s)) == 0 ||
				    wait_s < next - now) {
					continue; /* config changed, or re-evaluate hourly */
				}
			}
		}

		struct measurement m;
		struct record r;

		if (cal_live_is_on()) {
			LOG_WRN("scheduled measurement skipped: live mode active");
			k_sleep(K_SECONDS(60));
			continue;
		}
		led_pulse(50);
		if (app_measure_and_store(false, &m, &r) == 0) {
			LOG_INF("record %u stored (%u total)", r.seq, storage_record_count());
		}
		measure_print(&m, printk_out, NULL);
	}
	return 0;
}

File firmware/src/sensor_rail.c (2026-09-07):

/* Sensor rail control - see sensor_rail.h */

#include <zephyr/kernel.h>
#include <zephyr/device.h>
#include <zephyr/drivers/gpio.h>
#include <zephyr/pm/device.h>
#include <zephyr/logging/log.h>
#include <errno.h>

#include "sensor_rail.h"
#include "lidar.h"

LOG_MODULE_REGISTER(sensor_rail, CONFIG_LOG_DEFAULT_LEVEL);

static const struct gpio_dt_spec sensor_en =
	GPIO_DT_SPEC_GET(DT_PATH(zephyr_user), sensor_en_gpios);
static const struct device *const sensor_uart =
	DEVICE_DT_GET(DT_ALIAS(lidar_uart));

static bool rail_on;

/*
 * Suspending the nRF UARTE applies its "sleep" pinctrl state, which
 * disconnects TX/RX (input buffer off, no pull). That is what makes the
 * rail cut safe: nothing can leak into the powered-down sensor via R7.
 */
static int uart_park(void)
{
	int ret = pm_device_action_run(sensor_uart, PM_DEVICE_ACTION_SUSPEND);

	if (ret == -EALREADY) {
		ret = 0;
	}
	if (ret) {
		LOG_ERR("UART suspend failed (%d)", ret);
	}
	return ret;
}

static int uart_wake(void)
{
	int ret = pm_device_action_run(sensor_uart, PM_DEVICE_ACTION_RESUME);

	if (ret == -EALREADY) {
		ret = 0;
	}
	if (ret) {
		LOG_ERR("UART resume failed (%d)", ret);
	}
	return ret;
}

int sensor_rail_init(void)
{
	int ret;

	if (!gpio_is_ready_dt(&sensor_en)) {
		LOG_ERR("SENSOR_EN GPIO not ready");
		return -ENODEV;
	}
	if (!device_is_ready(sensor_uart)) {
		LOG_ERR("sensor UART not ready");
		return -ENODEV;
	}

	ret = gpio_pin_configure_dt(&sensor_en, GPIO_OUTPUT_INACTIVE);
	if (ret) {
		LOG_ERR("SENSOR_EN configure failed (%d)", ret);
		return ret;
	}
	rail_on = false;

	/* The UART driver comes up active (TX idle high) - park it right away. */
	return uart_park();
}

int sensor_rail_on(void)
{
	int ret;

	if (rail_on) {
		return 0;
	}

	ret = gpio_pin_set_dt(&sensor_en, 1);
	if (ret) {
		return ret;
	}
	rail_on = true;
	LOG_DBG("rail ON, settling %d ms", CONFIG_SNOWGAUGE_RAIL_SETTLE_MS);
	k_sleep(K_MSEC(CONFIG_SNOWGAUGE_RAIL_SETTLE_MS));

	ret = uart_wake();
	if (ret) {
		return ret;
	}
	/* Sensor-specific "start streaming" (TSD20); no-op for the TFmini. */
	ret = lidar_start();
	if (ret) {
		LOG_WRN("lidar_start failed (%d)", ret);
	}
	return ret;
}

int sensor_rail_off(void)
{
	int ret;

	if (!rail_on) {
		return 0;
	}

	/* Order matters: UART pins Hi-Z first, then cut the rail. */
	ret = uart_park();
	(void)gpio_pin_set_dt(&sensor_en, 0);
	rail_on = false;
	LOG_DBG("rail OFF");

	return ret;
}

bool sensor_rail_is_on(void)
{
	return rail_on;
}

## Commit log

2026-09-02 Spec v0.9: close U6/U7 (Zephyr+MCUboot, BLE DFU, SMP protocol); add TFmini Plus assembly manual
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2026-09-02 Add KiCad PCB v1.0: scripted board generation, DRC clean, JLCPCB gerber package
    [SnowGauge.kicad_pcb]
2026-09-02 Compact PCB v1.1: 64x50mm (35% smaller), fits BCAP091208G; DRC clean
    [SnowGauge.kicad_pcb]
2026-09-02 Fix mounting hole edge offset in PCB README (3.5mm all edges)
2026-09-02 PCB v1.2: divider fed from VBAT_SW (fix ADC overvoltage, drop Q3/R6/D3), clear USB corridor, silk fixes; add breadboard wiring guide
    [SnowGauge.kicad_pcb]
2026-09-02 PCB v1.2: terminals -> 3x 5.08mm 2P blocks (J1/J2/J4), silk adjustments
    [SnowGauge.kicad_pcb]
2026-09-02 PCB v1.2: TFmini terminals as contiguous 4P footprint for interlocked 2Px2 blocks
    [SnowGauge.kicad_pcb]
2026-09-02 Spec v0.10 (record PCB v1.2 changes); add CLAUDE.md handoff for firmware development
2026-09-02 Firmware step 1: Zephyr scaffold, sensor rail, TFmini driver, battery ADC, USB shell
    - NCS v3.4.0, board xiao_ble/nrf52840/sense, builds clean (FLASH 13%)
    - sensor_rail: D10 SENSOR_EN; TFmini UART suspended (pins Hi-Z) before
    the rail is cut, parked at boot
    - tfmini: interrupt-driven 9-byte frame parser, N-sample burst with
    median/variance/strength/temperature and quality counters
    - battery: A0 SAADC (gain 1/6, 40us acq), valid only while rail is on
    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
2026-09-03 Breadboard guide: regenerate from a scripted netlist with per-step figures and explicit hole labels
    - docs/gen_breadboard.py is now the source; every part/jumper end is drawn
    at its exact hole with the hole name printed next to it
    - one overview figure + one figure per assembly step (current step in
    colour, earlier steps greyed)
    - tables list end A / end B holes explicitly
    - fixed two physically impossible placements in the old guide: C6 shared
    holes with U1 (now b10-b12), R1 shared c33 with Q1 (now e33-e36)
    - battery-divider check now also probes c33 / a32; USB+bench-supply note
2026-09-03 Breadboard guide: STEP 2 check is 3V3 voltage, not LED (SnowGauge FW drives no LED)
2026-09-03 Breadboard guide: fix XIAO row order (USB left: top row 5V..D7, bottom row D0..D6) and reroute
    - 3V3/GND jumpers now go to the XIAO's top-row columns (a22, a21)
    - switch block (Q2, R3, R4) moved to the upper bank; bottom rails unused
    - A0 jumper to g20, R7/TFmini white on the lower bank (D6 is bottom row),
    TFmini green to a26 (D7 is top row)
    - 35 numbered items
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2026-09-03 Firmware step 2: TiltSensor abstraction with LSM6DS3TR-C, measure cycle, dfu/tilt shell commands
    - tilt.h / tilt_lsm6dsl.c: accel-only burst read at 52 Hz, averaged,
    powered down between readings; tilt/pitch/roll/die temperature
    - IMU uses zephyr,deferred-init and is initialised from tilt_init()
    after 30 ms (board regulator start-up delay is too short)
    - measure: tilt -> rail on -> Vbat -> TFmini burst -> Vbat -> rail off
    - shell: tilt [n], dfu (reboot into Adafruit bootloader for serial DFU),
    rail status prints the SENSOR_EN pin state; sensor/device shells on
    - verified on the breadboard: tilt 1.8 deg, 1020 mg on Z, 24.8 C
    [main.c, shell_cmds.c]
2026-09-03 Firmware step 3 prep: QSPI deep power-down, IMU supply gating, LED pulse, auto-60s test overlay
    - power.c: P25Q16H suspended (DPD) at boot; green LED pulse helper
    - tilt: IMU regulator (P1.08) switched off between readings
    (CONFIG_SNOWGAUGE_IMU_POWER_GATE, default y); verified readings survive
    the power cycles
    - overlay-auto60.conf: 60 s automatic measurement for sleep-current tests
    - main: LED pulse at each automatic measurement
2026-09-03 Firmware step 3: gate USB on VBUS (sleep 1.89 mA -> 17 uA), measure at auto start; record breadboard current measurements
    - usb_pm.c: CDC_ACM_SERIAL_ENABLE_AT_BOOT=n; enable usbd on VBUS_READY /
    disable on VBUS_REMOVED, enable at boot if VBUS already present
    - main: first automatic measurement right after boot
    - docs/measurements: picowatt method (difference measurement) and results
2026-09-03 Firmware step 4a: record storage (LittleFS on QSPI + internal-flash mirror), wall clock, rec/time shell commands
    - record.c: 40-byte little-endian record v1 with CRC-16 (docs/record_format.md)
    - storage.c: LittleFS /lfs/rec_YYYYMM.bin on the 2 MB QSPI, raw append-only
    mirror in a new internal-flash partition 0x9F000-0xEC000 (app shrunk to
    480 kB); restores clock estimate and sequence counter at boot
    - timekeeping.c: rtc-emul behind the rtc alias (UNSET/ESTIMATED/SYNCED)
    - QSPI deep power-down now via driver runtime PM (pm-device-runtime-auto)
    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
2026-09-03 Firmware step 4a: review fixes and bench verification
    - runtime PM limited to the QSPI flash (CONFIG_PM_DEVICE_RUNTIME_DEFAULT_ENABLE=n):
    the UARTE driver otherwise re-activates the TFmini UART with the rail off
    - clock is k_uptime based (rtc-emul gains ~2.6 s/day); rtc-emul only mirrored
    - storage_append: mirror is best effort once LittleFS is up; full-mirror warning once
    - record_print: correct sign for -1 < x < 0 fixed-point values
    - shell: 'rec hex', 'reboot', stricter 'time' arguments
    - decode_records.py: Zephyr crc16_ccitt is the reflected CCITT (verified against device bytes)
    - verified on the breadboard: persistence across DFU reflash and reset, clock
    restore (ESTIMATED), erase,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
    [decode_records.py, record.h, shell_cmds.c]
2026-09-03 Measurements: sleep current unchanged (18 uA) with FW step 4a record storage
2026-09-03 Firmware step 4b: BLE status advertising (Manufacturer Data), 'ble' shell command
    - ble_adv.c: connectable advertising 1-2 s (Kconfig / 'ble adv <ms>'), name SG-XXXX
    from the device ID, 16-byte Manufacturer Data (company 0xFFFF): vbat, record
    count, last distance, status flags, last epoch, uptime; refreshed per record
    - verified on the breadboard over the USB shell (payload decodes as expected);
    current increment to be measured next
2026-09-03 Docs: step 4b advertising current (+8 uA, 26 uA total); handoff update
2026-09-03 Firmware step 4c: SMP/mcumgr over BLE (fs download, os echo/datetime/reset)
    - smp_mgmt.c: datetime hooks keep the uptime-based clock and rtc-emul in step
    (SET -> time_set(synced), GET -> re-seed rtc-emul first)
    - SMP service UUID added to the scan response for nRF Connect Device Manager
    - larger ACL/L2CAP buffers for download speed; fs group up to 4 GB files
    - builds (285 kB flash, 80 kB RAM); not yet tested on the board
2026-09-03 Storage: mount LittleFS at /lfs1 (path hard-coded by nRF Connect Device Manager)
2026-09-03 Step 4c verified: SMP over the USB shell transport, tools/smp_datetime.py; docs
    - CONFIG_MCUMGR_TRANSPORT_SHELL=y so smpclient on the dev PC can drive
    echo/datetime over USB (Device Manager has no datetime UI)
    - verified: Android Device Manager echo + download of /lfs1/rec_202609.bin;
    datetime set via SMP switches the clock to SYNCED
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2026-09-03 App: header/disabled-button styling, shorter reference button label
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2026-09-04 Robustness pass (review findings): sensor mutex, low-battery capture guard, boot hold-off with reset counter, cal work queue + busy/seq status, live resume only while connected, ERASE gated on a down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
    [main.c]
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2026-09-04 Docs overhaul: start-here README, user guides 01-05 (parts/assembly/firmware/app/data), docs index with maintenance map, Pages landing, spec v0.12, firmware/app READMEs, archive of pre-v1.2 assembly 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
    - new: docs/README.md (doc list + what-to-update-when map), docs/index.html, docs/01_parts.md/.csv, 02_assembly.md, 03_firmware.md, 04_app.md, 05_data.md, docs/archive/
    - spec: v0.11 -> v0.12 full revision (sensor A/B TSD20, implemented sequence, record/schedule/clock model, BOM quantities for v1.2, measured power, BLE/page design, robustness, milestones)
    - firmware binaries published as GitHub Release fw-2026-09-04 and linked from t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
    [01_parts.csv]
2026-09-04 Parts list: purchase links for C6, 100 k, battery box/snap, terminal blocks, sockets, header; battery brands; breadboard consumables marked generic
    [01_parts.csv]
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2026-09-07 TSD20 current measurements, TFmini re-verification, release fw-2026-09-07 references
    - docs/measurements/2026-09-07_tsd20_breadboard_current.md (+ 900 Hz burst data):
    one TSD20 cycle 0.95 s / 42 mA / 0.0098 mAh, sleep + advertising 36 uA +-10.
    - Spec v0.13 section 7.1 and history, tsd20_protocol.md, firmware/README, CLAUDE.md
    updated; TFmini build re-verified on the breadboard after the lidar refactor.
    - Release references moved to fw-2026-09-07 (TFmini + _tsd20 assets).
    [2026-09-07_tsd20_burst_900Hz.csv]
2026-09-07 Watchdog + boot diagnostics: HW WDT supervisor, fatal-error reboot, reset cause, boot.log, crash test commands
    - wdt_mon.c: nRF52 WDT 120 s (runs in sleep), supervisor on the system
    work queue feeds only while the scheduler loop (2 h), a running
    measurement (60 s) and BLE advertising are alive; shell 'wdt [stall ch]'
    - diag.c: reset cause via hwinfo (cleared after reading), own
    k_sys_fatal_error_handler that reboots with the reason in GPREGRET2,
    consecutive-reset counter in NVS ('sgd/boots' - GPREGRET2 is wiped by a
    watchdog reset, measured), hold-off moved here, measurements halted
    after CONFIG_SNOWGAUGE_BOOT_MAX_RESETS (12), one line per boot in
    /lfs1/boot.log (rotated at 8 k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
    [main.c, shell_cmds.c]
2026-09-07 Measurements: sleep current with the WDT build 22 uA +-10 (no increase); spec U13 closed
    [2026-09-07_wdt_sleep_raw1.csv, 2026-09-07_wdt_sleep_raw2.csv, 2026-09-07_wdt_sleep_zero.csv]
2026-09-07 Sensor no-response retry (one power cycle, record flag RETRIED) and hourly clock checkpoint in NVS
    - measure.c: 0 frames -> lidar_stop() (TSD20 stop command), rail off for
    CONFIG_SNOWGAUGE_LIDAR_RETRY_OFF_MS (1 s), rail on (start), capture once
    more; record flag bit 7 RETRIED, decoder + page (sw cache v9) updated
    - timekeeping.c: checkpoint sgt/epoch every CONFIG_SNOWGAUGE_TIME_SAVE_MIN
    (60 min) and 2 s after an external sync; time_restore_saved() after
    config_init takes the later of the newest record and the checkpoint
    - Verified on the TFmini breadboard: time set -> reboot restores the
    synced time from the checkpoint (not the 2 h older record); capture at a
    wrong baud -> retry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
    [decode_records.py, lidar.c, main.c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]
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2026-09-07 Coordinate system doc with PCB render figure; LiDAR axis is IMU +Y (label fix, math unchanged)
    - docs/coordinate_system.md: mounting orientation, measured IMU axes
    (+Y down = laser, +X toward the battery side, +Z component side),
    tilt / pitch / roll definitions, bench note, old-vs-new table
    - docs/assets/figures/coordinate_system.png from kicad-cli pcb render
    - Kconfig symbol SNOWGAUGE_SENSOR_AXIS_POS_Y (was NEG_Y: the accelerometer
    reads +1 g on the axis pointing up, so ay = -1 g means +Y points down)
    - linked from docs/README.md (docs map + update map), 02_assembly, 04_app,
    05_data, record_format, firmware/README, spec, CLAUDE.md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
    [shell_cmds.c]
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2026-09-11 App: save on iOS through the share sheet, and a CSV encoding choice
    Two field problems from the 2026-09-11 phone test:
    - iPhone (Bluefy): "ダウンロードして CSV 保存" saved nothing and raised no
    error. WKWebView silently ignores <a download>. saveFiles() now offers
    navigator.share({files}) on iOS - as a button, because the share call needs
    live user activation and the BLE read takes tens of seconds - plus copy and
    new-tab fallbacks. The anchor is still clicked but stays detached on iOS so
    WKWebView cannot navigate to the blob and drop the BLE session.
    - Android: the CSV opened as mojibake with "ï»¿" in front of device_id, i.e.
    the viewer ignored the BOM and read Lati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
2026-09-11 App: show the CSV text view on every platform (mojibake self-check)
    All three encodings came back garbled on the user's Android viewer, and the
    UTF-8 BOM showed as "ï»¿" - the viewer decodes Latin-1 whatever the file
    says. The upload/download path is byte-clean (TextEncoder -> CBOR byte string
    -> SMP), so the saved file is fine; what the field needs is a way to tell a
    broken file from a broken viewer. The save panel (CSV text view, copy, open in
    a new tab) is therefore no longer iOS-only; only the share button and its help
    line stay iOS-only.
    Version 2026-09-11b, sw cache v12.
2026-09-11 App: revert the diagnostic panel, keep two CSV encodings
    The check is done, so the save panel goes back to iOS-only and the encoding
    picker back to two entries. Measured with site name テスト, the file itself is
    correct everywhere:
    - Google Sheets on the desktop: correct.
    - Excel for Mac: 繝せ繝 - it reads CSV as Shift_JIS whatever the BOM says, so
    the Shift_JIS export is what that case needs.
    - Sheets on Android: ãƒ†ã‚¹ãƒˆ - it reads Latin-1 whatever the file contains,
    so no encoding helps; open the CSV on a PC.
    UTF-8 without the BOM helped nobody and is dropped. Docs carry the table.
    Version 2026-09-11c, sw cache v13.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
2026-09-11 Reset backoff: clear on a real measurement or a BLE connection, not a timer
    The bench PCB stopped measuring entirely today: one record at 15:05 and
    nothing for the next 26 minutes, confirmed with a picowatt capture that shows
    no current above 5 mA. Power-cycling the board while wiring the meter had
    driven the consecutive-reset counter to 12, which halts scheduled
    measurements, and the single record was the manual one from the app's ZERO
    (cal_zero() bypasses the halt check; its timestamp, 15:04, matches).
    Reviewed and applied by Codex, with a host regression test:
    - The counter is cleared by a measurement that actually ran the sensor rail
    and stored its record, not by a 10-minute timer. T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
    [2026-09-11_pcb_5min_1h_1Hz.csv, 2026-09-11_pcb_burst_119Hz.csv]
